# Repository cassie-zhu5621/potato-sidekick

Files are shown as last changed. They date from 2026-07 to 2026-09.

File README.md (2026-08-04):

# NoticeBot-Potato2.0

A placed sidekick that watches for one thing you asked it to watch for, and tells you
when it happens in real-time.

You say *"the roundtable area at my lab — people usually have meetings here."*
The robot turns its head across the room, photographs each angle, and sends the
five independent images to Gemini in a **single** call. Gemini enumerates what is there, sorts it
into what matters and what is only context, and compiles your sentence into a
**watch-spec** over an eleven-row vocabulary of social relations (gaze, joint
attention, pointing, F-formation, turn-taking …). CV then evaluates that spec
frame by frame, at the angle that looked richest. When the spec is satisfied the
robot collects a short photo story of the moment and looks up at you.

   what is interesting is: 
      1.you can read and argue with what it decided to watch for
      2.the whole human-robot-collaboration loop of notice delegation

---

## The hardware list

This is v2, the 3-DOF lamp form.

| | |
|---|---|
| Motions | 3 × Feetech **SCS0009** serial-bus servos — pan(id:1) / tilt(id:2) / nod(id:3) |
| Bus | **FE-URT2-C001** USB↔TTL adapter, 1 Mbaud, external 5–6 V on the servo rail |
| Head camera | **InnoMaker OV4688** UVC module, 4 MP, H-FOV 58° |
| Microcontroller | **M5Stack CoreS3** — screen, speaker, TTP223 body-tap sensor, Grove Chainable RGB LED (P9813) |
| Body | simply designed 3-DOF lamp form (built in rhino)|
| Reasoning Brain | laptop. Everything runs here; the boards are I/O. |

---

## Running it

**On a new machine, start at `docs/GETTING_STARTED.md`.

```bash
pip install -r requirements.txt

# tier 0 — logic only, no hardware at all
python3 tests/test_session_flow.py

# tier 1 — MOTION ONLY. Servos and nothing else: no camera, no VLM, no API key.
export NOTICEBOT_PORT=/dev/cu.usbmodemXXXXX     
python3 robot/clip_player.py S7a                # one state
python3 robot/clip_player.py                    # every state
python3 robot/clip_player.py --all --cores3 /dev/cu.usbmodemXXXX     # every state, with LED and sound

# tier 2 — the full loop
export GEMINI_API_KEY=...                               # Planner + five-frame confirm
python3 noticebot_loop.py --cam 0 --cores3 /dev/cu.usbmodemXXXX --serve --feedback console
```

Before trusting a session: `python3 robot/tools/preflight.py` — a check for connection. will print a GO if everything's ok.

### Local CV smoke test

The default detector is Grounding DINO; MediaPipe Tasks supplies pose and face
landmarks. Bring up only that stack, without the robot, camera, VLM API, or
speech dependencies:

```bash
python3 -m venv .venv
.venv/bin/pip install -r requirements-cv.txt
.venv/bin/python -m pytest tests/test_cv_unit.py -q
.venv/bin/python perception/cv_smoke_test.py path/to/person.jpg \
  --vocab person,cup,laptop

# optional faster open-vocabulary adapter (same smoke-test contract)
.venv/bin/python perception/cv_smoke_test.py path/to/person.jpg \
  --detector yoloworld --vocab person,cup,laptop
```

The first real run downloads `IDEA-Research/grounding-dino-tiny` into the local
Hugging Face cache. Later runs are local. Inspect `session_feed/cv_smoke/result.json`
and `overlay.jpg` for boxes, pose, face count, device, and per-stage latency.

The explicit real-model integration test uses the same function:

```bash
CV_TEST_IMAGE=path/to/person.jpg .venv/bin/python -m pytest \
  tests/test_cv_integration.py -m integration -s
```

That integration test exercises both Grounding DINO and YOLO-World. Grounding
DINO remains the default; choose `--detector yoloworld` when latency matters.

### Gemini video trigger smoke test

Put `GEMINI_API_KEY=...` in the ignored `.env` file, then pass one local video and
one text trigger condition:

```bash
python3 planning/gemini_video_trigger.py path/to/video.mp4 \
  "当有人挥手时触发反馈"
```

The default model is `gemini-3.5-flash`, with minimal
thinking, low media resolution, a 256-token output cap, and priority service
tier. Every value can be overridden through `.env` or CLI flags. The command
prints structured JSON containing `feedback_trigger`, confidence,
evidence timestamps, and a short Chinese feedback message. The uploaded test file
is deleted from the Gemini Files API after the request.

---

## What is where

```
noticebot_loop.py   MAIN — the only process
robot/              servos: bus, calibration, clip playback, firmware, CAD
motion/             the movement design: Blender sources, generators, clips
perception/         CV: detectors, pose, the 11-row relation engine
planning/           VLM: the planner, the relevance layer, the sweep
session/            the state machine, speech, storyboard, CoreS3, the feed
webui/              the researcher's browser view
docs/               specs and setup
tests/              pure-logic tests, no hardware needed
```

Every package's `__init__.py` says in a few lines what that package owns and what
each file in it does. Start there, then `docs/ARCHITECTURE.md` for how the layers
hand off.

---

## How to work on this
(manage the folders properly!!!)
| If you are changing… | you live in | you should not need to touch |
|---|---|---|
| how the robot moves | `motion/`, `robot/` | perception, planning |
| what counts as a relation | `perception/` | motion, the web UI |
| what the VLM is asked, and how its answer is compiled | `planning/` | motion, firmware |
| the interaction — screens, timing, sound | `session/`, `robot/firmware/` | perception |
| what the researcher sees | `webui/` | everything else |

!!!!!!!!!!!!Three important conventions: breaking each one has already cost us a day!!!!!!!!!!!!

1. **The CSVs in `motion/clips/` are build artefacts. Never hand-edit one.**
   To change a movement, edit the `.blend` in `motion/src/` (or the generator in
   `motion/blender/`) and re-export. A hand-edited CSV looks fine, then disagrees
   with the file it came from, and nobody can tell afterwards which one is real.

2. **`robot/calibration.py` describes THIS physical build.** Those numbers were
   *measured*, with `robot/tools/jog.py` — not chosen. If you rebuild the neck,
   re-measure. Do not nudge values until it looks right.

3. **One owner per channel.** The screen belongs to the state machine, the
   antenna's colour to the state table, its brightness to the playing clip.

---

## Specs

- `docs/GETTING_STARTED.md` — **start here on a new machine**
- `docs/ARCHITECTURE.md` — the four layers and what crosses between them
- `docs/INTERACTION_SPEC.md` — every trigger, screen and timeout, and why
- `docs/HARDWARE_SETUP.md` — wiring, servo IDs, calibration, flashing
- `docs/MOTION_AUTHORING.md` — the Blender workflow
- `docs/relation_table.md` — the eleven-row relation vocabulary, with citations
- `docs/TEST_PLAN.md` — pre-test finished, replace with user study design?

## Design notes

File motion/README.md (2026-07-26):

# motion — the movement design

```
src/        one .blend per state (plus rig.blend, the master rig)
blender/    scripts run INSIDE Blender: the rig builders, the clip generators,
            and export_clip.py
clips/      the exported CSVs the robot actually plays -- BUILD ARTEFACTS
```

Read `../docs/MOTION_AUTHORING.md` before changing anything here. The one rule:
never hand-edit a file in `clips/`.

A CSV row is `t_ms, pan_deg, tilt_deg, nod_deg, pan_unit, tilt_unit, nod_unit,
led`. `*_deg` is Blender's frame (positive nod = UP); `*_unit` is the Feetech
0-1023 position with the rig zero at 512. `led` is the antenna envelope, 0-255,
authored alongside the motion so the light and the movement cannot drift apart.

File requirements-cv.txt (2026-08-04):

# Local CV stack: Grounding DINO + MediaPipe Tasks + tests.
# Install this file instead of the full robot/speech stack when bringing up CV.
numpy
opencv-contrib-python
mediapipe
torch
transformers
pillow
ultralytics
pytest

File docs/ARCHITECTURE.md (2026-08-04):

# Architecture

Four layers, one conductor. `noticebot_loop.py` is the only long-running process;
everything else is a library it drives.

```
                       ┌──────────────────────────────┐
   participant ──PTT──▶│  session/   state machine    │◀── researcher (webui/)
   participant ──tap──▶│  S1…S8, screens, sound, STT  │
                       └───────┬──────────────┬───────┘
                    state name │              │ request text
                               ▼              ▼
                       ┌───────────────┐  ┌──────────────────────┐
                       │   robot/      │  │     planning/        │
                       │ clip player   │  │ sweep → ONE Gemini call│
                       │ → SCS0009 ×3  │  │ → watch-spec + tiers │
                       └───────┬───────┘  └──────────┬───────────┘
                     pose, deg │                     │ detect / focus vocab
                               ▼                     ▼
                       ┌──────────────────────────────────────────┐
                       │            perception/                   │
                       │ detector → scene graph → 11-row truth    │
                       │ → WatchExecutor → fired entries          │
                       └──────────────────┬───────────────────────┘
                                          │ a finding
                                          ▼
                              session/storyboard → session/feed
```

## The order of a round, and why it is that order

**S1 idle → S2 listen.** PTT held on the CoreS3. Audio is captured on the
*laptop* mic, not the board: 16 kHz 16-bit mono is 32 kB/s and the serial link
carries about 14 kB/s.

**S2 → S3 acknowledge.** Whisper returns text. The nod and "I heard you." are one
act and neither happens until the words exist — nodding earlier would claim
understanding of something not yet read. Unusable text (silence, one syllable,
punctuation) goes to S8 instead, visibly.

**S3 → S4 plan.** The head sweeps its stations and grabs **one pure frame per
station** — no detector, nothing drawn. Annotating a frame before the model reads
it feeds our own guesses back as its judgement.

**End of S4: the single Gemini call.** The five raw frames are sent as separately
labelled spatial images in one request. A grid is written only for local researcher
visualization and is not model input. Back comes:

- `seen` — everything in the room
- `detect` — context tier: enriches, cannot trigger
- `focus` — may trigger
- `boxes` — per object, mapped back to the angle it came from
- `watch` — the compiled spec, over rows 1–11

**S4 → S5 track.** The clip ends before the VLM does, so the head **holds the last
angle it swept** and the screen keeps saying `planning...`. Only when the answer
lands does it turn to the richest-scoring angle and say `tracking...`. Claiming to
track while the answer is in flight is a statement about the robot's state that
is simply untrue.

**S5 watching.** `focus`/`detect` become the detector's vocabulary — `set_vocab`
for an open-vocab model, a synonym-expanded whitelist for closed COCO YOLO. Each
settled frame produces a truth vector; `WatchExecutor` decides which entries are
satisfied; `_focus_ok` refuses any gaze or point that did not land on a focus
object. Without that last gate, "someone looked at something" fires on every
chair in the room.

**A fired entry → candidate → Gemini confirm.** A raw-frame ring buffer selects
five ordered frames at t−1, t−0.5, onset, t+0.5 and t+1 seconds. Only a confirmed
candidate is reported. The safe default is one console feedback line; S7 motion
requires explicit `--feedback robot`.

**S6, "not that one."** A body tap during S5. The watch-spec survives; only the
direction changes. If nobody answers within 15 s the robot moves to the *next-best*
angle from the sweep rather than back to the rejected one.

## Rules that cross layer boundaries

**Frames are only used when the head is still.** `settled_ms > SETTLE_MS`. A
frame grabbed mid-move is blurred *and* attributed to a pose the head has already
left.

**Perception may fail forever without anything else noticing.** The state
machine, the screens and the researcher's keys do not depend on it. A run that
dies mid-study costs a participant.

**Every finding goes through one door.** A watch entry firing, the researcher's
`f` key and a forced state all reach `session/feed.py` the same way. When the
storyboard hung off the detector while the screen counter hung off the state
machine, the board read 3 and the feed read 0 — they were counting different
events.

**One owner per channel.** Screen ← state machine. Antenna colour ← state table.
Antenna brightness ← the playing clip. Sound ← the clip's `sfx`. The v1 firmware
had legacy commands that set colour and text as *side effects*, which is how S6's
red negation got painted blue.

## Testing without hardware

`session/session_flow.py` contains the transition rules and nothing else — no
serial port, no frame grab, no sleep. `tests/test_session_flow.py` drives it with
a fake clock, 86 assertions. The awkward paths (STOP mid-scan, a transcript that
arrives after its timeout, a tap in the wrong state) are exactly the ones that are
tedious to trigger by hand and the ones a participant finds in five minutes.

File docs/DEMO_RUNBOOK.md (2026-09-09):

# DEMO RUNBOOK — the exhibition stand

Branch `demo-expo-2026`. The user-study build is `cassie/tomato`, tagged
`s2-study-build`; nothing here is meant to go back to it.

**The robot is unchanged** — same firmware, same English screen, same faces.
Everything a visitor reads is on the iPad, so translating the stand means
translating one file (`webui/booth.py`, the `CHOICES` list at the top).

---

## 0. Once — the touch sensor

A TTP223 capacitive module on the head. The only hardware the demo adds, and the
firmware already supports it (`USE_TAP 1`, `TAP_SRC 1`).

```
SIG -> GPIO 17   (Grove Port C)
VCC -> 3V3       NOT 5V. ESP32 GPIO is not 5 V tolerant.
GND -> GND
```

Check it before anything else:

```bash
python3 robot/tools/touch_test.py --cores3 /dev/cu.usbmodem11201
```

One `IN BODYTAP` per touch. Random 0/1 with nothing touching means SIG is not
reaching the pin. **No sensor to hand?** Set `TAP_SRC 2` in the `.ino` and
reflash — the onboard IMU reports a knock instead, no wiring at all.

---

## 1. Each morning — is the VLM fast today?

```bash
python3 -m robot.tools.net_check
```

Read **FLOOR** (see §2b of the main RUNBOOK):

| FLOOR | what it means |
|---|---|
| 1–2 s | planning will be 5–8 s. The sweep screen carries it easily. |
| 7–10 s | planning will be ~20 s. Still works; stand next to the visitor and talk over it. |

A slow FLOOR is Google queueing and **cannot be fixed from here** — not by the
network, not by the tier, not by sending fewer frames. Measured across two days:
RTT 0.03 s while FLOOR swung 1.3 → 20 s, and a hotspot made RTT *worse* without
touching FLOOR.

**Do not change `NOTICEBOT_GEMINI_MODEL`.**

---

## 2. Start it — ONE terminal, all day

```bash
cd ~/Documents/Claude/Projects/potatobot/notice-sidekick-runkit
git checkout demo-expo-2026

python3 noticebot_loop.py \
    --cam 0 \
    --cores3 /dev/cu.usbmodem11201 \
    --detector yoloworld \
    --cv-hz 4 \
    --feedback robot \
    --serve --conf 0.2
```

Identical to the study command. It prints two addresses:

```
open  http://localhost:8000                 <- the researcher's page
      http://192.168.x.x:8000/booth         <- type THIS on the iPad
```

**Do not restart between visitors.** Every story lands in one
`attention_log.jsonl`, and the day's wall on the tablet is that file. A restart
opens a new session folder and the wall goes empty.

There is no second terminal. The study's file server (main RUNBOOK §4b) serves a
static page that must outlive a loop restart; the tablet has to *control* the
loop, so it lives in the same server.

---

## 3. The iPad

Open the printed address in Safari, then once:

1. **共有 → ホーム画面に追加.** Opening from the Home Screen is full-screen with
   no address bar, so a visitor cannot navigate away.
2. **設定 → アクセシビリティ → アクセスガイド** on. Triple-click to lock it to
   the page.
3. **設定 → 画面表示と明るさ → 自動ロック → なし.**

### Bring your own network

Venue Wi-Fi very often has **client isolation**: two devices on the same SSID
cannot reach each other, and there is no fixing it on the day. Bring a travel
router or use a phone hotspot, and put the laptop and the iPad both on it with
the laptop reaching the internet through the same box.

Test before doors open: if `localhost:8000/booth` works on the laptop and the
iPad hangs, it is isolation.

---

## 4. What a visitor does

```
   ねている        Idle. Sleeping face on the robot AND on the iPad --
                   (-_-) z z z and one line: あたまに そっとさわって
                   ください. No menu: a stand with a list of options on
                   it is a kiosk.
1  頭にさわる      Tap -> it lifts out of the bow and looks up, and the
                   THREE CHOICES appear on the iPad.                    (S2)
                   The tap has a consequence on both screens at once,
                   which is what teaches the gesture.
2  iPadで選ぶ      Three Japanese sentences. Tapping posts the ENGLISH
                   one through the same door speech uses, so the planner
                   really compiles it.
3  うなずく        Acknowledge. 1.7 s, no page of its own -- the strip
                   shows ^o^ and the page stays put.                    (S3)
4  部屋を見る      Scan. Five stations appear on the iPad as they are
                   captured; when the plan lands the boxes are drawn and
                   the chosen one goes red.                             (S4)
5  見張る          Watch. SAME SCREEN. The red cell is now the LIVE
                   camera; the other four stay as sweep stills.         (S5)
   頭にさわる      -> Correct. It looks elsewhere and the red frame moves
                   with it.                                             (S6)
6  よぶ            Call. Chirp + lean. The same prompt appears on the
                   iPad and on the robot's screen.                      (S7)
7  OK             Either screen. The robot nods and goes straight back
                   to watching; the TABLET stays behind and waits for
                   the report -- 6-45 s, with a face and a moving bar.
8  Then the story: the strip at full height, swiped sideways, sentence
   underneath.  とじる returns to the choose screen.
```

**The tap means two things and the robot decides which** — asleep it means "look
at me", watching it means "not that one". Both are the same sentence: put your
attention where I am pointing it.

### The two extra touches on the room screen

- **Tap the red cell** → the live view fills the screen, everything else dims to
  10–14%, and the rule stays lit in the sixth cell. Tap again to go back.
- **The sixth cell is the rule** — relation chips that light as each becomes
  true, the AND/OR/THEN between them, and the object they are bound to. This is
  what tells a visitor *how to trigger it*, and it is the panel to point at when
  somebody asks how it works.

### The top strip

```
[-_-] [._.] [^o^] [・・・] [o_o] [>_<] [\^o^/]              [☰ 3]
ねてる きづいた わかった みてる  みはり ちがう よんでる        きろく
```

The faces are copied from the firmware's `uiFace()` — the same characters the
robot's own screen shows, so a visitor looking from one to the other sees the
same thing twice. `☰` opens the day's stories; it hides itself while open.

---

## 4b. The keys, from the terminal

They work in the terminal the loop was launched from — no need to click the
preview window first.

| key | does |
|---|---|
| `1`…`8`, `0` | force a state (1 Idle · 2 Attend · 3 Acknowledge · 4 Scan · 5 Watch · 0 Settle · 6 Correct · 7 Call · 8 Error) |
| `g` | S2_LISTEN — the same lift the head tap produces, for testing without the sensor |
| `f` | force a finding — the keyboard twin of **notice this NOW** |
| `r` | torque off (press a state key to re-engage) |
| `q` | quit |

Useful before the sensor is wired: `g` → tap a choice on the iPad → `f` → OK.
That walks the whole demo without touching the robot.

---

## 4c. Your break — the stand runs itself

```bash
# stop the loop first: Ctrl-C. Both open the same two serial ports.
python3 -m robot.tools.attract
```

Walks the whole eight-state cycle — motion, screen, light and sound together —
and loops until Ctrl-C. About 55 s a pass. `--gap 1.5` slows it, `--once` does a
single pass.

Each beat waits for its clip to finish and *then* holds, so a gesture is never
cut off mid-turn. Clip lengths are read from the CSVs at startup rather than
kept in a table, so re-exporting from Blender cannot make the timing stale.

A motionless robot on a table reads as broken, and one that only moves when
somebody works the tablet is invisible from across the hall.

**It is NOT the system.** No camera, no VLM, no watch-spec, nothing recorded —
authored clips on a timer. The board shows `DEMO LOOP` and the terminal says so
too, because at a research stand that reading has to be corrected before it is
made, not after somebody has told a colleague about it. If anyone asks whether
it is really watching right now: no, and start the real loop to show them.

Ctrl-C releases the joints, so the head does not fight the next person who picks
the robot up to look underneath.

---

## 5. When it does not fire

Both controls are on the **laptop's** page (`http://localhost:8000`, LIVE tab,
**IF IT MISSES THE SCENE**):

- **notice this NOW** — skips the trigger and the confirmation judge. The robot
  performs the notice and collects the story exactly as if it had fired. The
  visitor cannot tell.
- **look around again** — a fresh sweep on the same request.

Give it ten seconds first. A real trigger is better than a forced one, and the
visitor is usually still reading the tablet.

---

## 6. What is different from the study build

Worth knowing, because someone will ask:

| | study | stand |
|---|---|---|
| brief | spoken, Whisper | two Japanese buttons → the same English sentence → the same planner |
| `REPLAN_PERIOD_S` | 540 s — one self-directed sweep per session | **0** — at a stand it lands mid-visit and reads as a fault |
| tablet | review page only, second process | the whole interface, in the loop's server |
| head tap | Correct only | Correct **and** wake |

The VLM path is **byte-identical** to `s2-study-build`: `perception/`,
`planning/planner.py`, `planning/judge.py`, `planning/provider.py`,
`planning/gemini_provider.py`, `robot/`, `motion/` — no diff. The only change
under `planning/` is `sweep_plan.py` recording its own output directory, which
no prompt ever sees.

---

## 7. Changing the wording

`webui/booth.py`, `CHOICES` at the top. Japanese for the visitor, English for
the planner; **the planner never sees Japanese**. Restart the loop.

The three shipped are:

| | asks for | why |
|---|---|---|
| 荷物に触ったら教えて | hands-on the visitor's own bag | "that is mine" is what makes delegating mean anything |
| 人が集まったら教えて | gathering | ambient; a crowded hall supplies it for free |
| ポスターの前で発表がはじまったら教えて | people gathering **in front of a poster** | **the room the stand is actually in** — presentations start at the posters all day. Costs the visitor nothing to arrange, happens whether or not anyone waits for it, and makes the point better than a staged event could. Bound to the poster, which is what keeps it from compiling to the same entry as `gather` |

Keep it to three or fewer. A visitor deciding between two or three things reads
them; a visitor deciding between five picks the first one.

---

## 8. End of the day

Ctrl-C once. The teardown flushes any story still collecting, so the last
finding of the day is on disk rather than lost with the process.

`session_feed/<run>/` is the whole day: every report, every sweep, every LLM
call, and `review.html`.

---

## Troubleshooting

| symptom | first suspect |
|---|---|
| iPad hangs, laptop is fine | venue Wi-Fi client isolation (§3) |
| tablet stuck on the choose screen | the loop is not publishing — check the terminal for a traceback |
| tapping the head does nothing | `touch_test.py` first; then whether the robot is in the state that accepts it |
| nod, then sleep, no sweep | an `arm_next` ordering regression — every caller must `request()` first and `arm_next()` second |
| the wall is empty | the loop was restarted; the wall is one `attention_log.jsonl` |
| planning takes 20 s | `net_check`. If FLOOR is high it is Google, and nothing here helps |
| the live cell flickers black | the stream got moved inside the markup `render()` rewrites — it must stay outside `#app` |
| in `attract`, the screen changes but nothing moves | `player.start()` is missing — `request()` only records what the player should do; a worker thread feeds the bus. It looks exactly like a servo-power fault and is not |
| the robot fights your hand | you are in `attract` and it has not been Ctrl-C'd, or a state key re-engaged torque. `r` releases |
| keyboard keys do nothing | fixed 2026-09-09 — the terminal used to be read only under `--no-view`, so with a preview window open `f`, `g` and the state numbers only worked when THAT window had focus. If it regresses, look for an `a.no_view` gate on `stdin_key()` |

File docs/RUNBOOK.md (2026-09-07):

# RUNBOOK — bringing the robot up, in order

The order matters. Each step isolates one layer, so that when something breaks
you already know which layer it is in. Skipping to step 3 and debugging from
there is how a servo problem gets mistaken for a CV problem.

`MACHINE_E2E_READINESS.md` is the longer bring-up narrative; this is the short
version you run every time.

---

## 0. Once per machine — dependencies

```bash
conda activate sidekick
cd ~/Documents/Claude/Projects/potatobot/notice-sidekick-runkit

pip3 install -r requirements.txt -r requirements-cv.txt
pip3 install feetech-servo-sdk python-dotenv google-genai ultralytics
```

The second line is the packages whose **pip name differs from their import
name**, or that the requirements files miss. They were each discovered the hard
way — one at a time, mid-run, after the robot had already been woken up:

| pip name | import name | why it is not obvious |
|---|---|---|
| `feetech-servo-sdk` | `scservo_sdk` | `pip install scservo-sdk` installs nothing useful |
| `python-dotenv` | `dotenv` | missing from `requirements.txt` |
| `google-genai` | `google.genai` | `google` is a namespace package, so it "exists" while empty — the error says `cannot import name 'genai'`, not "not installed" |
| `ultralytics` | `ultralytics` | only needed for `--detector yoloworld` |

Also: `.env` must exist (copy `.env.example`, add `GEMINI_API_KEY`). Not needed
for `--offline`.

### Which LLM answers

One variable, read in one place (`planning/provider.py`). Unset means Gemini, so
a fresh clone and the other machine behave exactly as before.

```
NOTICEBOT_LLM_PROVIDER=gemini       # default
NOTICEBOT_LLM_PROVIDER=anthropic    # + ANTHROPIC_API_KEY, + pip3 install anthropic
```

Try a provider **before** a session, on a sweep that already happened, rather
than discovering it with a participant in the room:

```bash
python3 robot/tools/provider_ab.py                    # newest recorded sweep
python3 robot/tools/provider_ab.py --provider both    # re-run both, live
```

The provider also selects the station-scoring rule (`planning/station_score.py`),
because that rule counts boxes and the two models do not box at the same density
— Gemini's is kept verbatim, Anthropic's caps what context boxes can contribute.
`plan.json` records both, and the sweep line prints them.

It prints the recorded answer beside the new one: latency, violations, watch
entries, boxes. **The boxes are the ones to read.** Their coordinate convention
lives in the prompt, not in the schema, so a model that reads it differently
returns numbers that are individually plausible and jointly wrong — a failure
that passes validation, passes the test suite, and shows up as the robot aiming
confidently at nothing.

---

## 1. No hardware — 30 seconds

```bash
python3 -m robot.states              # state table vs clips vs source literals
python3 tests/test_session_flow.py   # pytest CANNOT collect this one
python3 -m pytest -q
```

`test_session_flow.py` is an old-style script with no `test_` functions, so
`pytest` reports "no tests ran" and moves on. It is the only test of the state
machine. **Run it separately or it is silently skipped.**

Run this before touching the robot. It catches a broken state table, a stale
clip, and a mistyped state name — none of which need a servo to find.

---

## 2. Hardware health

```bash
python3 noticebot_loop.py --list-cams        # confirm the head cam's index
python3 robot/tools/preflight.py --cam 0     # bus / calibration / clips / camera
```

Wants `GO`. Notes:

- The head camera is the one that **actually delivers 2560×1440**. The built-in
  returns a square frame (Center Stage). Indices move whenever anything USB is
  replugged, so this is a per-session check, not a number to write down.
- Voltage: `< 5.5` warns, `< 5.0` fails. **Under-voltage does not raise — it
  makes the motion soft, slow and short of its target, which reads exactly like
  a calibration error.** Swap the pack before blaming a curve.

---

## 2b. Is the VLM fast today? — 40 seconds, before the participant arrives

```bash
python3 -m robot.tools.net_check          # 5 reps; pass a number for more
```

Planning latency is **not stable across days and is not ours to control**. On
2026-08-17 the planner's median went from 5.7 s (the previous week) to 18.6 s,
peaking at 49 s, with nothing changed on our side — same model, same thinking
level, same ~5460 input tokens. Knowing that at 09:00 is a schedule decision;
finding out at 14:05 with somebody in the chair is a lost session.

Three numbers, because they fail for different reasons:

| | what it measures | reading |
|---|---|---|
| **RTT** | TCP+TLS to the endpoint. No API key, no quota | `> 1 s` → the network. Try a hotspot |
| **FLOOR** | a call with a ~100-byte payload and an 11-token answer | `> 4 s` → **Google is queueing.** Nothing on this machine helps |
| **LOADED** | the same call carrying five real JPEGs, ~530 KB | `LOADED − FLOOR` big → the uplink or image ingestion |

It prints a verdict. **A slow FLOOR is the common case and it is not fixable** —
bandwidth cannot explain seconds for a hundred bytes. Measured 2026-08-17: Wi-Fi
RTT 0.03 s with FLOOR 7.7 s, and a hotspot made RTT *worse* (0.11 s) without
touching FLOOR. Do not go looking for a better connection.

**What to do when FLOOR is slow**

- Budget ~20 s for brief→watch and **push E1's cue later**, so the actor is not
  playing the scene while the robot is still sweeping.
- Do **not** change `NOTICEBOT_GEMINI_MODEL` mid-study, however tempting. Half of
  S2 is already on `gemini-3.5-flash`; a model change splits the dataset and
  makes the planner's relation choices incomparable across participants. (3.5 is
  two generations behind as of 2026-08-13 — 3.6 shipped 07-21, 3.7 on 08-13 —
  which is the most likely reason it is being served slowly. It is still not
  worth the confound.)
- Check <https://status.cloud.google.com/> — but the 08-17 slowdown was never
  posted there, so an all-green status page is not evidence.

---

## 3. Motion only — no perception, no cloud

```bash
python3 robot/clip_player.py --cores3 /dev/cu.usbmodem11201
```

Walks the whole CYCLE and reports lag and dropped frames.

**Pass: 0 dropped, worst lag under 20 ms.**

This is the step that separates *servo / power / timing* from *perception /
planning*. If it is clean here, no later motion problem is the detector's fault.
Single clips for a faster look:

```bash
python3 robot/clip_player.py S7a    # the most demanding: pan peaks at 121 deg/s
python3 robot/clip_player.py S7b    # holds the deep -22 lean under load
python3 robot/clip_player.py S4_PLAN
```

LED-only, touching no servos — separates "firmware not reflashed" from
everything else:

```bash
python3 robot/clip_player.py --led-test --cores3 /dev/cu.usbmodem11201
```

---

## 4. Full loop

```bash
python3 noticebot_loop.py \
    --cam 0 \
    --cores3 /dev/cu.usbmodem11201 \
    --detector yoloworld \
    --cv-hz 4 \
    --feedback robot \
    --serve
```

Web UI at **http://localhost:8000** — live view, plan, feed, and the context box
(type a request there instead of speaking).

| flag | why |
|---|---|
| `--detector yoloworld --cv-hz 4` | the detector, and the only one. Now also the default; `gdino` is kept selectable for reproducing old logs and is never run |
| `--feedback robot` | let a confirmed finding drive S7. `console` prints the judgment and moves nothing |
| `--offline` | no Gemini; use it to prove the mechanics before adding cloud latency |
| `--no-stt` | skip Whisper; type into the web context box |
| `--cores3 <port>` | explicit beats auto-detect when you already know the port |

```
1-8 force a state · 0 S5a · f manual finding · c cycle · r relax · q quit
```

Those keys are read from the **OpenCV preview window** when it is open, and from
the **terminal** when it is not (`stdin_key()`, cbreak on a tty). So `--no-view`
costs the preview window, not the override — earlier revisions of this file said
it "takes the keyboard with it", which was never true of the code.

**Use `--no-view` whenever `--serve` is on.** The OpenCV window is a native
window and can never render inside the browser page; leaving it open just means
two copies of the same stream, one of which steals focus. The web UI has already
had the live view at `/stream.mjpg` since it was written. With `--no-view
--serve` the annotated frame is still computed and published — the flag suppresses
the window, not the overlay.

---

## 4b. The participant's screen — a SECOND terminal

The tablet beside the robot shows the reports. It needs a plain file server,
because `file://` forbids the `fetch` the page uses to notice new reports:

```bash
cd ~/Documents/Claude/Projects/potatobot/notice-sidekick-runkit/session_feed && \
python3 -m http.server 8765 --bind 0.0.0.0
```

**The full path and the `&&` both matter.** This was two lines with a relative
`cd`, and run from anywhere but the project's parent the `cd` fails while the
shell goes on to the next line anyway — so the server comes up happily, serving
whatever directory you happened to be in. It looks like it worked; the tablet
just says 404 for `latest.html`. Hit on 2026-08-17 from the home directory.

Leave it running all day. Point the tablet at, once, and never again:

```
http://localhost:8765/latest.html      # on the laptop itself, or a Sidecar iPad
http://<laptop-ip>:8765/latest.html    # ipconfig getifaddr en0
```

`latest.html` follows `current.txt`, which the loop rewrites at startup, so it
tracks the current run across participants and across restarts without anybody
retyping a session name.

**A SEPARATE PROCESS ON PURPOSE.** Serving this from the `--serve` web UI would
be one window fewer and was rejected for it: the two would then die together, and
the moment that matters is a mid-session restart of the loop. The participant is
sitting in front of the tablet; it should keep showing the last report rather
than "cannot connect".

**Do not put this on the participant's phone.** The questionnaire's
imagined-camera block and interview Q6 both turn on the contrast with *phone
alerts*; delivering the reports by phone answers that question before it is
asked. A fixed screen that is not theirs is the point.

If the tablet cannot reach the laptop, suspect the venue's WiFi before anything
else — campus networks commonly isolate clients from each other, and then no IP
will work. `curl -sI http://<laptop-ip>:8765/latest.html` FROM THE LAPTOP splits
it: a 200 means the server and firewall are fine and the block is between the
devices. Sidecar, or a phone hotspot both machines join, sidesteps it entirely.

---

## 5. Shut down — every time

```bash
python3 robot/tools/play_on_hardware.py --relax
```

Ctrl-C runs the cleanup. **Closing the terminal window or `pkill` does not**:
the `finally` block never executes, so torque stays on and the servos hold their
last pose, heating, and the CoreS3 keeps whatever colour it was showing. Check by
hand — a relaxed neck moves freely.

---

## Reading a failure

| symptom | first suspect |
|---|---|
| `no CoreS3 found` | another process owns the port (Arduino IDE's serial monitor); then firmware |
| tablet says "waiting for a session…" forever | the loop has not started, or it is writing to a `--feed-dir` outside `session_feed/`. `cat session_feed/current.txt` |
| tablet shows the previous participant's reports | the loop never started for this one; `current.txt` is written before anything else can fail, so it is a run that did not run |
| tablet page never updates | opened as `file://`, not through the server — `fetch` is blocked there and the poll dies silently |
| planning takes 20–50 s and the participant is waiting | almost never ours. `python3 -m robot.tools.net_check` (§2b). A slow FLOOR is Google queueing and cannot be fixed from here |
| `404` for `latest.html` on a server that started fine | the `cd` failed and the shell ran `http.server` anyway, so it is serving the wrong directory. The 404 line is the give-away: the server is up, the file is not there. Use the full path with `&&` (§4b) |
| `PONG cores3_sidekick v4` after flashing | the board still has the old build; v5 is STOP-as-hold, OK-only on `noticed`, OK on `error` |
| LED never changes | no `--cores3`; then firmware; then a flat `led` column in the CSV (re-export) |
| transcript comes back empty | microphone permission for Terminal — macOS hands out a **silent stream** rather than an error |
| stuck on the `waiting` bar | Whisper is running; `stt_busy` postpones the 15 s deadline up to a 30 s ceiling. Press STOP: if it responds, the main loop is alive |
| motion soft / short of target | battery, not calibration |
| BODYTAP with nobody touching it | TTP223 SIG floating. Harmless in S1 — **in S5b every false tap is an S6** |
| `ignoring model '…' — not a Claude model` | a `NOTICEBOT_GEMINI_*` model variable is still set while the provider is `anthropic`. It is being dropped, which is the correct outcome; clear it to silence the line |
| `404` / `not_found_error` on the Anthropic path | the model name. `NOTICEBOT_ANTHROPIC_MODEL` overrides it without validation |
| `ran out of output budget` | raise `NOTICEBOT_ANTHROPIC_MAX_OUTPUT_TOKENS` (default 4096). On the Gemini path the same cause surfaces as `parse-fail: Expecting ',' delimiter` instead |

The run's artefacts, including every LLM call, land in
`session_feed/e2e_<timestamp>/`. Failed calls are audited too.

---

## Branches

Naming follows the existing `sonan/…` convention:

```bash
git checkout -b cassie/<what>
git add -A && git commit -m "..."
git push -u origin cassie/<what>

git fetch origin
git rebase origin/sonan/modification
```

Before pushing, the three checks from step 1. Note that changing
`generate_s4_sweep.py` **will** turn `test_sweep_plan.py` red: it hard-codes S4's
old structure (`led == 223`, a return of `> 200` units). That is the test
asserting the bug you are removing, and it has to be updated with the generator.

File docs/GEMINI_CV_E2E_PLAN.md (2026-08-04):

# NoticeBot Gemini + CV 重构与本机 E2E 计划

> 状态：Gemini production path 已实现；stable entity IDs 等增强项继续迭代  
> 分支：`sonen/modification`  
> 目标：用户用一句自然语言委托 NoticeBot；系统用本机 webcam、CV 和 Gemini 找到对应事件；确认后只在终端输出一行反馈，不控制舵机、CoreS3、灯光或声音。

真机到货后的安全顺序、GO/NO-GO 和剩余接口见 `docs/MACHINE_E2E_READINESS.md`。

## 0. 一句话版本

```text
用户输入 → Gemini 看 5 个空间视角并生成可执行 Plan → CV 在本地约 1 Hz 持续观察
→ CV 候选事件触发 → 取同一视角前后 5 帧给 Gemini 确认 → 终端输出一行反馈
```

核心原则：**Gemini 负责理解“用户想看什么”和最终确认；CV 负责低成本、持续地找候选事件。** Gemini 不逐帧运行。

---

## 1. 当前代码和目标架构的区别

| 项目 | 迁移前 | 当前实现 |
|---|---|---|
| Planner 模型 | Anthropic Claude | Gemini，模型名可通过环境变量切换 |
| Planning 图像 | 多视角拼成 1 张 contact sheet | 5 张独立空间帧，在同一次 Gemini 请求中依次传入 |
| CV 输出 | 全局 `relation_id -> bool` | 带人物、目标物、时间和证据的 `RelationFact` |
| 触发后流程 | CV fired 后直接进入 finding/story | CV 先生成 candidate，再由 Gemini 看 5 张时间帧确认 |
| Judge | Anthropic；主要在 story 最后调用 | Gemini；在进入 finding 前调用，返回结构化 JSON |
| 用户反馈 | Story/feed，以及机器人动作 | MVP 只输出一行：`[FEEDBACK] ...` |
| 纯电脑 webcam E2E | 主入口仍强制连接舵机，不能真正独立运行 | 增加 `--robot none --feedback console` |
| Gemini 视频脚本 | 已有独立 smoke test，上传整段本地视频 | 保留作实验工具；正式实时链路使用 5 张图片，不上传持续视频 |

`planning/gemini_video_trigger.py` 保留为独立 whole-video smoke test；production 主循环通过共享 Gemini provider 完成独立空间图片 Planning 和五时间帧 Confirm。

---

## 2. 会用到哪些 Service、Key 和本地组件

### 2.1 Service / Key 总表

| Service / 组件 | 用途 | 是否联网 | 需要的 Key / 配置 | MVP 是否必须 |
|---|---|---:|---|---:|
| Gemini Developer API | 5 视角 Planning；5 时间帧 Event Confirm；生成一行反馈 | 是 | `GEMINI_API_KEY`、`NOTICEBOT_GEMINI_MODEL` | 是 |
| OpenCV | webcam 读取、帧缓存、JPEG 编码、预览和 overlay | 否 | camera index，如 `--cam 0` | 是 |
| MediaPipe | Face landmarks、head pose、人体 pose、手腕/肩/髋关键点 | 首次模型准备后本地 | 无 Key；模型在 `perception/weights/` | 是 |
| Ultralytics YOLO-World | 可切换的低延迟 open-vocabulary detector；后续可接 ByteTrack | 首次下载权重时联网 | 无 Key；公开权重自动下载 | 否，但保留并测试接口 |
| Grounding DINO | open-vocabulary detector 备选 | 首次下载模型时联网 | 公开模型通常无需 Key；必要时可用 `HF_TOKEN` | 否 |
| faster-whisper | 本地语音转文字 | 首次下载模型时联网 | 无 Key；`NOTICEBOT_WHISPER`、`NOTICEBOT_LANG` | 否，本机测试先文字输入 |
| Web UI | 输入用户请求、查看 raw/overlay、Plan 和事件 | 否 | `--serve --web-port 8000` | 建议 |
| Servo / CoreS3 | 机器人转头、屏幕、灯光、声音 | 否 | 串口配置 | 此阶段不使用 |
| 数据库 / 云存储 | 不需要；Plan、事件、图片先写本地 | 否 | 无 | 否 |

Gemini 参考文档：[Models](https://ai.google.dev/gemini-api/docs/models)、[多图理解](https://ai.google.dev/gemini-api/docs/image-understanding)、[Structured Output](https://ai.google.dev/gemini-api/docs/structured-output)。

### 2.2 推荐环境变量

`.env` 只放本机秘密，不进入 Git：

```dotenv
GEMINI_API_KEY=replace_with_your_real_key

# 不把模型名写死在业务代码里。低延迟 smoke test 使用 Flash-Lite；
# 若账户可用模型不同，只改这里。
NOTICEBOT_GEMINI_MODEL=gemini-3.5-flash
NOTICEBOT_GEMINI_THINKING_LEVEL=minimal
NOTICEBOT_GEMINI_MEDIA_RESOLUTION=low
NOTICEBOT_GEMINI_MAX_OUTPUT_TOKENS=256
NOTICEBOT_GEMINI_SERVICE_TIER=priority

# 本机默认参数，不是秘密
NOTICEBOT_CAMERA=0
NOTICEBOT_CV_HZ=4
NOTICEBOT_LANG=zh
NOTICEBOT_FEEDBACK=console
```

兼容现有 smoke test 时，可以暂时同时支持 `GEMINI_MODEL`；重构完成后统一为 `NOTICEBOT_GEMINI_MODEL`。

### 2.3 Key 管理规则

1. 仓库只提交 `.env.example`，绝不提交 `.env`。
2. Key 只在 provider 初始化时读取；不能放进 prompt、Plan JSON、日志或 Web UI state。
3. 启动时只打印 `Gemini configured: yes/no`，不能打印 Key 的任何片段。
4. API 错误日志要过滤 request headers 和完整 payload。
5. 测试使用 fake provider，不依赖真实 Key，也不产生费用。
6. 如果 Key 曾被提交或贴进聊天，应立即在 Google AI Studio 撤销并重新生成。
7. 后续部署到共享机器时用系统 secret manager；本机 prototype 用 ignored `.env` 足够。

---

## 3. CV 包括什么

| CV 模块 | 输入 | 输出 | 建议实现 |
|---|---|---|---|
| Camera | webcam 原始视频，通常约 30 FPS | timestamped BGR frame | OpenCV `VideoCapture` |
| Frame sampler | camera frame | 默认 1 Hz perception frame；5 张 planning/event frame | OpenCV + ring buffer |
| Object detector | perception frame | 带置信度的物体 boxes | 默认 Grounding DINO；保留已测试的 YOLO-World adapter |
| Tracker | 连续 detections | 稳定的 `person_1`、`laptop_1` 等 entity id | Ultralytics ByteTrack，先不加新包 |
| Face / gaze | frame + person | face、head pose、gaze ray | MediaPipe FaceLandmarker + OpenCV geometry |
| Body pose | frame + person | shoulders、hips、elbows、wrists | MediaPipe PoseLandmarker |
| Relation evaluators | entities + tracks + pose | `RelationFact[]` | 11 个固定 evaluator |
| Trigger matcher | Plan + RelationFact stream | `EventCandidate` | onset + persist + sequence + cooldown |
| Event frame buffer | timestamped raw frames | 同一视角的 5 张时间帧 | 内存 ring buffer |
| Overlay | detections + tracks + facts | 只供人调试的画面 | OpenCV；绝不作为 Gemini 原始输入 |

### 3.1 11 种关系

| ID | Relation | 主要 CV 证据 | 是否需要目标绑定 |
|---:|---|---|---:|
| 1 | gazing-at | face/head ray 命中 object box | 是 |
| 2 | joint-attention | 两条 gaze ray 指向同一 target | 可选 |
| 3 | eye-contact | face forward 指向 camera | 否 |
| 4 | pointing/reaching | elbow→wrist ray 命中 target | 可选 |
| 5 | proxemic-zone | 人际距离 / shoulder width | 否 |
| 6 | F-formation | 多人朝向和共同 o-space | 否 |
| 7 | approach/depart | tracked distance 在时间窗内单调变化 | 可选 |
| 8 | lean-in | torso angle 朝指定 work surface / object | 是 |
| 9 | hands-on | wrist 进入/接近指定 object box 并持续 | 是 |
| 10 | gathering | person count 或 group cluster 改变 | 否 |
| 11 | turn-taking | 指定 shared artifact 的 controller id 改变 | 是 |

不要只输出 `truth[9] = true`。目标格式是：

```json
{
  "relation_id": 9,
  "relation_key": "hands_on",
  "subject_id": "person_1",
  "target_entity_id": "laptop_1",
  "confidence": 0.86,
  "started_at": 1720000000.25,
  "observed_at": 1720000001.25,
  "evidence": {
    "wrist": "right",
    "wrist_inside_target": true,
    "held_for_s": 1.0
  }
}
```

这样 `hands-on laptop` 不会被“手碰到了 cup”错误触发；`then` 也能保证是同一个 tracked person 完成前后动作。

### 3.2 采样率

| 数据 | 建议采样方式 | 原因 |
|---|---|---|
| webcam capture | 相机原生约 30 FPS | 让预览和 ring buffer 连续 |
| CV inference | Grounding DINO 接受约 **1 Hz**；YOLO-World 接口可切换到更高频率 | 用户选择准确/open-vocab 优先，同时保留低延迟路径 |
| Planning frames | 用户输入后 **5 张空间帧**，每个视角 1 张 settled raw frame | 看完整环境，不是时间序列 |
| Event frames | 候选 onset 周围 **5 张时间帧**：`t-1.0, t-0.5, t0, t+0.5, t+1.0 s` | 看 before / during / after |
| Gemini calls | 每次新 Plan 1 次；每个通过本地 gate 的 candidate 最多 1 次 | 不逐帧调用，控制延迟与费用 |

CV 的推理频率不代表相机帧率。相机仍连续采集；Grounding DINO 可以约 1 Hz 运行，YOLO-World 在需要低延迟时通过同一 detector interface 切换。Event buffer 从 raw stream 里按目标 timestamp 选最近的 5 帧。

---

## 4. 两类“五帧”到底是什么

### A. Planning 的 5 张空间帧

```text
view_1(-60°) → view_2(-30°) → view_3(0°) → view_4(+30°) → view_5(+60°)
```

它们是**大致同一时段、不同观察角度**。目的：让 Gemini 理解房间里有哪些人和物、用户说的对象在哪个视角、接下来应该监视哪里。

无机器人时，webcam 不能自己转头，因此提供两种模式：

- `--planning-view fixed`：复制/采集同一 webcam 方向的 5 张短间隔帧，用于最简单 E2E；不声称覆盖整个房间。
- `--planning-view manual`：UI 提示用户把 webcam/电脑依次朝 5 个方向，每次按空格采一张，更接近真实 sweep。

有机器人后再恢复 5 个 pan station 的自动 sweep。

### B. Event Judge 的 5 张时间帧

```text
t-1.0s → t-0.5s → t0(candidate onset) → t+0.5s → t+1.0s
```

它们是**同一观察角度、不同时间**。目的：确认动作是否真的发生以及方向，例如 approach 还是 depart、谁把 control 交给了谁。

五张图片都作为独立 image part 放在同一次 Gemini 请求中，并在每张图前放一个明确 label；不拼图，不逐张发五次 API。

---

## 5. Tentative Prompts

Prompt 不应要求模型暴露 chain-of-thought。我们给模型的是可审核的 `evidence_chain` 定义，并让它只返回结构化结论和短理由。

### 5.1 Planner Prompt

**调用时机：** 用户提交新请求，5 张空间帧准备好后。  
**输入：** 用户原句、relation catalog 的紧凑版本、5 张带 view id 的原始图片、JSON schema。  
**输出：** `PlanV2`。

Tentative system prompt：

```text
You are the planning component of a camera-based attention assistant.
Convert the user's request into a small executable watch plan using only the
provided relation catalog. Do not invent relation IDs or visual capabilities.

The five images are different spatial views, not a temporal video.
First identify relevant entities and assign stable IDs within each view.
Then choose at most three watch rules. Bind every object-directed relation to
a concrete target entity. Use the simplest rule that expresses the request.

If the request cannot be represented or an entity is not visible, report that
explicitly in missing_capabilities or assumptions. Return only schema-valid JSON.
```

动态 user payload：

```text
USER_REQUEST: 帮我看有没有人开始用我的电脑
RELATION_CATALOG_VERSION: 2.2
RELATION_CATALOG: <compact JSON>

IMAGE view_1, camera_role=planning, pan=-60
<image>
...
IMAGE view_5, camera_role=planning, pan=+60
<image>
```

建议输出：

```json
{
  "schema_version": "2.0",
  "normalized_request": "发现有人开始操作用户的电脑",
  "entities": [
    {"entity_id": "laptop_1", "label": "laptop", "view_id": "view_3", "box": [0.42, 0.30, 0.75, 0.72]}
  ],
  "best_view_id": "view_3",
  "watch_rules": [
    {
      "rule_id": "rule_1",
      "label": "someone starts using the laptop",
      "then": [
        {"relation_id": 8, "subject": "person:any", "target_entity_id": "laptop_1"},
        {"relation_id": 9, "subject": "same_as_previous", "target_entity_id": "laptop_1"}
      ],
      "within_s": 4.0,
      "persist_frames": 2,
      "cooldown_s": 15
    }
  ],
  "assumptions": [],
  "missing_capabilities": []
}
```

### 5.2 Plan Repair Prompt

只有 validator 拒绝第一次输出时调用一次：

```text
Your previous plan was not executable.
Validation errors:
- rule_1 condition 2 requires target_entity_id
- relation_id 14 does not exist

Repair only these errors. Keep the user's intent and visible entity IDs.
Return only a complete schema-valid PlanV2 JSON object.
```

第二次仍不合法时，不安装 bad plan：保留上一份 valid plan，或进入 safe fallback 并在 UI 显示错误。

### 5.3 Event Confirm + Feedback Prompt

**调用时机：** 本地 CV matcher 通过 relation、entity binding、persist、onset、cooldown 和画质 gate 后。  
**输入：** 原始用户请求、当前 rule、CV facts、5 张时间帧。  
**输出：** `EventDecision`。确认和一行反馈合并为一次 API call。

```text
You are a strict visual event verifier.
The five images are ordered temporal evidence from the same camera view.
Decide whether the requested event actually occurred and whether the subject
and target match the rule. CV facts are candidate evidence, not ground truth.

Return confirmed=false when evidence is ambiguous, target identity is wrong,
the required order is reversed, or the event is visible in only one noisy frame.
Do not infer actions outside the images. The feedback must be one short Chinese
sentence suitable for printing directly to the user. Return only JSON.
```

Payload outline：

```text
USER_REQUEST: 帮我看有没有人开始用我的电脑
RULE: <rule_1 JSON>
CV_FACTS: <bound RelationFact JSON array>

IMAGE event_t_minus_1_0s
<image>
IMAGE event_t_minus_0_5s
<image>
IMAGE event_t_0_onset
<image>
IMAGE event_t_plus_0_5s
<image>
IMAGE event_t_plus_1_0s
<image>
```

输出 schema：

```json
{
  "confirmed": true,
  "confidence": 0.91,
  "matched_rule_id": "rule_1",
  "subject_id": "person_1",
  "target_entity_id": "laptop_1",
  "evidence_frame_ids": ["event_t_0_onset", "event_t_plus_0_5s"],
  "reason": "同一人靠近并连续触碰指定电脑",
  "feedback": "我看到有人开始使用你的电脑了。"
}
```

### 5.4 Audit Prompt（非 MVP）

只有“画面里持续有人，但所有关系长时间为 false”时低频抽样，询问是否存在 vocabulary 未覆盖的重要事件。它用于研究 relation coverage，不参与第一版实时链路。

---

## 6. 调用表

| 阶段 | Trigger | 本地输入 | API 输入 | 结构化输出 | 下一步 |
|---|---|---|---|---|---|
| User input | UI submit / CLI text | 用户原句 | 无 | request id | 开始取 planning views |
| Planning | 5 个 view ready | request + 5 raw images + relation catalog | Gemini 1 call，5 image parts | `PlanV2` | validator |
| Validation | Planner 返回 | PlanV2 + evaluator registry | 无 | valid plan / errors | install 或 repair once |
| CV watch | valid plan installed | webcam + 默认 1 Hz entities/tracks | 无 | `RelationFact[]` | matcher |
| Candidate | rule 从 false→true 且 persist 达标 | facts + rule + ring buffer | 无 | `EventCandidate` | 等待后两张时间帧 |
| Confirm | 5 event frames ready | request + rule + facts + 5 raw images | Gemini 1 call，5 image parts | `EventDecision` | confirmed gate |
| Feedback | `confirmed=true` | decision.feedback | 无 | 一行 stdout | cooldown，继续 watching |
| Reject | `confirmed=false` | decision + reason | 无 | debug log，不通知用户 | 继续 watching |

反馈动作在本阶段固定为：

```text
[FEEDBACK] 我看到有人开始使用你的电脑了。
```

不调用 `robot/`、CoreS3、LED、speaker 或 motion clip。

---

## 7. Trigger 机制

```mermaid
flowchart TD
    A["CV produces bound RelationFacts at configured rate"] --> B{"Rule and target binding match?"}
    B -- No --> A
    B -- Yes --> C{"Persist for N frames?"}
    C -- No --> A
    C -- Yes --> D{"False → true onset?"}
    D -- No --> A
    D -- Yes --> E{"Rule cooldown clear?"}
    E -- No --> A
    E -- Yes --> F{"Camera settled and frame quality OK?"}
    F -- No --> A
    F -- Yes --> G["Create EventCandidate"]
    G --> H["Collect 5 temporal frames around onset"]
    H --> I["Gemini Event Confirm"]
    I --> J{"confirmed?"}
    J -- No --> A
    J -- Yes --> K["Print one feedback line"]
    K --> L["Start rule + subject + target cooldown"]
    L --> A
```

Candidate key 应该是 `(rule_id, subject_id, target_entity_id)`，而不是只有 relation id。这样不同人、不同物体之间不会共享错误 cooldown。

---

## 8. Relation Catalog：JSON single source of truth

新增 `schemas/relation_catalog.v2.json`。每个 relation 包含：

```json
{
  "id": 9,
  "key": "hands_on",
  "name": "hands-on / manipulating",
  "subject_type": "person",
  "target_type": ["object"],
  "target_required": true,
  "variants": ["touch", "manipulate", "offer"],
  "evidence_chain": [
    "detect and track subject person",
    "detect and track target object",
    "estimate left and right wrist landmarks",
    "test wrist inside or near target box",
    "require the condition for at least 1.0 seconds"
  ],
  "negative_cases": [
    "wrist overlaps a different object",
    "single-frame accidental overlap",
    "target is occluded and identity is uncertain"
  ],
  "evaluator": "hands_on_v2"
}
```

JSON 定义“关系是什么意思、需要什么证据”；Python evaluator 真正执行几何计算。启动时 registry 检查 catalog 中每个可用 relation 都有实现，防止 Prompt 宣称能检测但代码里没有 evaluator。

---

## 9. Proposal 的代码改动

### 9.1 建议目录

```text
schemas/
  relation_catalog.v2.json       # 11 种关系唯一语义来源
  plan_v2.py                     # Pydantic PlanV2
  relation_fact.py               # Pydantic RelationFact / EventCandidate
  event_decision.py              # Pydantic EventDecision

planning/
  prompt_builder.py              # compact catalog + multi-image payload
  validator.py                   # schema + semantic + capability validation
  compiler.py                    # PlanV2 -> executable rules
  providers/
    base.py                      # Planner/Judge provider interface
    gemini.py                    # Gemini implementation

perception/
  detector.py                    # detector interface and YOLO adapter
  tracker.py                     # ByteTrack entity IDs
  pose.py                        # MediaPipe face/body adapter
  relation_registry.py           # catalog key -> evaluator
  evaluators/                    # one relation evaluator per file/group

events/
  matcher.py                     # all/any/not/then + entity binding
  frame_buffer.py                # raw frame ring buffer
  candidate.py                   # onset/persist/cooldown/quality gate
  gemini_confirm.py              # five temporal images -> EventDecision

feedback/
  base.py
  console.py                     # MVP: print one line only
  robot.py                       # future; this阶段不调用
```

### 9.2 分阶段修改

| Phase | 改动 | 完成标准 |
|---:|---|---|
| 1 | Relation catalog、Pydantic schemas、validator、unit tests | 非法 relation、缺 target、反向 then 都会被拒绝 |
| 2 | Gemini provider + 5 张独立 planning images | 不再依赖 contact sheet；能稳定返回 PlanV2 |
| 3 | Tracker + bound RelationFact；旧 truth vector 暂时兼容 | rule 能绑定同一 person 和指定 object |
| 4 | Candidate matcher + 5-frame ring buffer | onset、persist、sequence、cooldown 均有单测 |
| 5 | Gemini event confirm 接到 finding 前面 | 未确认事件不会进入 feedback |
| 6 | `--robot none --feedback console` | 普通 laptop + webcam 可以跑完整链路 |
| 7 | 清理旧 Anthropic production path | 已完成；MVP 只需要 Gemini key |
| 8 | 真实机器人 adapter | 单独验收，不影响 webcam-only runner |

### 9.3 必须一起修的现有问题

- Planner invalid 会重试一次；仍 invalid 时不会 install。
- `_focus_ok` 目前没有对所有 object-directed relations 做严格 target binding。
- `then` 已改为严格顺序；反向或同时发生均为 false。
- Planner 后台线程带 request generation id，STOP 或新请求后丢弃旧结果。
- CV candidate 不能在 S6/S7 继续消耗一个用户还没看到的 cooldown。
- Gemini confirm 已发生在 finding/S7 之前。
- `duration_s` 要真正终止或重新规划，而不是只存在 JSON 中。
- 退出前要 flush/join 正在 finalize 的 event，避免最后一条记录丢失。

### 9.4 依赖建议

第一版需要：

```text
google-genai
python-dotenv
pydantic>=2
opencv-contrib-python
numpy
mediapipe
ultralytics
pytest
```

YOLO 自带 ByteTrack 接口，第一版不需要额外安装 DeepSORT。也先不要加入 SAM、CLIP、action-recognition、depth estimation；只有真实测试显示某个 relation 无法达到精度时再加。

---

## 10. 本机 webcam 的真实 E2E 怎么跑

### 10.1 当前马上可跑：Gemini 视频 smoke test

这只能验证“Gemini 看视频 + 用户 trigger + JSON 返回”，**不是完整 CV→candidate→5 frame confirm pipeline**。

```bash
cd /Users/zhangjianan/Desktop/HRI/potato-sidekick

python3 -m venv .venv
source .venv/bin/activate
pip install -r requirements.txt

cp .env.example .env
# 编辑 .env，填入 GEMINI_API_KEY

python3 planning/gemini_video_trigger.py /absolute/path/to/test.mp4 \
  "当有人开始使用我的电脑时告诉我"
```

预期输出：

```json
{
  "feedback_trigger": true,
  "confidence": 0.91,
  "evidence_timestamps": ["00:04"],
  "feedback": "我看到有人开始使用你的电脑了。",
  "reason": "视频中有人靠近并操作电脑"
}
```

### 10.2 重构完成后的目标 E2E 命令

先检查 webcam index：

```bash
python3 noticebot_loop.py --list-cams
```

运行电脑-only 模式：

```bash
python3 noticebot_loop.py \
  --cam 0 \
  --robot none \
  --input text \
  --feedback console \
  --detector yolo \
  --cv-hz 1 \
  --planning-view fixed \
  --serve
```

浏览器打开 `http://localhost:8000`，在 context 输入：

```text
帮我看有没有人开始使用我的电脑
```

真实运行顺序：

1. webcam 持续采集，Web UI 显示 raw preview。
2. 用户提交文字后，程序取得 5 张 planning spatial frames。
3. 一次 Gemini call 返回 entities、best view 和 watch rules。
4. validator 通过后才 install plan；UI 显示人类可读的 rule。
5. Grounding DINO + MediaPipe 默认约 1 Hz 输出 bound RelationFacts；需要更低延迟时切换 `--detector yoloworld`。
6. 当同一个人满足指定电脑的 rule，candidate gate 记录 onset。
7. ring buffer 取 onset 前两张，再等待后两张，共 5 张时间帧。
8. 一次 Gemini call 确认事件并返回 `EventDecision`。
9. 若 `confirmed=true`，终端输出：

   ```text
   [FEEDBACK] 我看到有人开始使用你的电脑了。
   ```

10. 系统进入该 `(rule, person, laptop)` 的 cooldown，然后继续观察。

### 10.3 推荐的第一次人工 E2E 场景

固定 webcam 对着桌面，保证一个人和 laptop 都完整入镜：

1. 先保持 3 秒无人触碰电脑，建立 negative baseline。
2. 一个人进入画面，走近 laptop。
3. 手放到键盘/触控板并操作 2 秒。
4. 期望只产生一个 candidate、一个 Gemini confirm、一个 feedback line。
5. 立即重复动作时应被 cooldown 抑制。
6. 手碰旁边的 cup 不应触发 laptop rule。
7. 把“先操作、再靠近”倒序表演，不应满足 `approach then hands-on`。

保存以下调试产物，但不保存 Key：

```text
runs/<run_id>/request.json
runs/<run_id>/plan.json
runs/<run_id>/relation_facts.jsonl
runs/<run_id>/candidates.jsonl
runs/<run_id>/decisions.jsonl
runs/<run_id>/events/<event_id>/frame_01.jpg ... frame_05.jpg
```

---

## 11. MVP 验收标准

- 只配置 `GEMINI_API_KEY` 就能运行 production VLM path。
- 主入口不连接机器人硬件也能启动。
- Planner 和 Judge 都使用 5 张独立图片，不依赖 contact sheet 或整段视频。
- CV 默认以约 1 Hz 运行，但 camera/ring buffer 保持连续帧；YOLO-World 可配置为 4 Hz。
- 每个 object-directed relation 都带正确 `target_entity_id`。
- 非法 Plan、反向 `then`、错误 target、单帧闪烁都不会产生反馈。
- Gemini 返回 `confirmed=false` 时用户不会收到反馈。
- 每个已确认事件只打印一行；没有 motion、LED、CoreS3 或声音副作用。
- 无 API key 的 unit/integration tests 使用 fake provider 并完全可重复。

## 12. 最终建议

先实现 Phase 1–6，形成一个可以在 laptop webcam 上反复测试的闭环，再接真实舵机和 CoreS3。最重要的边界不是换一个模型，而是把 **Plan schema、entity binding、candidate trigger、Gemini confirm、feedback adapter** 五个接口固定下来；这些接口稳定以后，Gemini 型号、detector 和机器人硬件都可以独立替换。

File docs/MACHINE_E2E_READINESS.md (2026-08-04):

# NoticeBot 真机 E2E Readiness 与到货测试清单

> 更新：2026-08-03  
> 分支：`sonen/modification`  
> 目标机器：3× SCS0009、FE-URT2、OV4688 head camera、M5Stack CoreS3、Mac laptop  
> 本文只讨论真机路径；Mac 内置 webcam 不是 blocker。

## 结论

软件路径已经具备一条命令完成目标 E2E 的接线；是否 GO 只剩真机到货后必须实际确认的电气、校准、串口、相机和机械安全：

```text
用户请求 → Gemini 五视角 Plan → 真机 CV watch → 五时间帧 Confirm
→ 只输出一行 feedback
```

当前大致状态：

| 层 | 状态 | 证据 / 缺口 |
|---|---|---|
| CV 模型本机加载 | 🟢 | Grounding DINO + MediaPipe、YOLO-World + MediaPipe 真实图片测试通过 |
| YOLO-World 接口 | 🟢 | 连续推理约 94–132 ms，动态 vocabulary 可用 |
| Gemini API | 🟢 | Flash-Lite、minimal thinking、low resolution、priority tier 真实调用通过 |
| SessionFlow | 🟢 | 逻辑测试全部通过 |
| 真机舵机/CoreS3/camera | ⚪ | 等机器到货才能验证 |
| 当前 `.venv` 硬件依赖 | 🟢 | full `requirements.txt` 已安装，`pip check` 通过 |
| 当前 production Planner | 🟢 | 主循环已调用 Gemini structured output |
| 五张独立 Planning 图片 | 🟢 | sweep 独立图片送 Gemini；grid 只作本地 debug |
| Candidate 五帧 Confirm | 🟢 | `t-1,-.5,0,+.5,+1` 已接在 finding 之前 |
| Plain-line feedback | 🟢 | 默认 `--feedback console`；不会进入 S7/CoreS3 feedback |

因此，明天正确目标是：**先得到每一层的 GO，再进行受控组合**。不要把所有未知量一次接上。

---

## P0：机器到之前的软件准备（已完成）

### P0.1 安装完整硬件运行依赖

当前 `.venv` 已补齐：

```text
scservo_sdk: OK
serial: OK
faster_whisper: OK
google.genai: OK
ultralytics: OK
mediapipe: OK
cv2: OK
```

其中：

- `feetech-servo-sdk`：舵机总线必须。
- `pyserial`：CoreS3 必须。
- `faster-whisper`：如果第一轮使用 Web UI 文字输入，可以暂缓。

安装命令：

```bash
cd /Users/zhangjianan/Desktop/HRI/potato-sidekick
source .venv/bin/activate
pip install -r requirements.txt
pip check
```

完成后至少确认：

```bash
python -c "import scservo_sdk, serial, google.genai, cv2, mediapipe"
```

### P0.2 明确明天测试的是哪条 VLM 路径

现在 production 统一为 Gemini；whole-video 脚本只作独立 smoke：

| 路径 | 当前状态 | 用途 |
|---|---|---|
| Gemini video trigger | 独立脚本、真实 API 已通过 | whole-video API smoke |
| Gemini 五图 Planner + 五图 Confirm | 已接 production 主循环 | 明天真机目标路径 |

如果明天主要测试真机动作和传感链路，建议第一轮设置：

```bash
python noticebot_loop.py ... --offline
```

这样先排除云端模型不确定性；`--offline` 现在同时覆盖 Planner 和 Judge。

真实语义 Planning 只需要 `.env` 中有效的 `GEMINI_API_KEY`。

### P0.3 增加安全的 feedback 模式

之前已经决定此阶段反馈只输出：

```text
[FEEDBACK] 我看到有人开始使用你的电脑了。
```

但当前主循环中，CV finding 会发出 `finding` event，并进入：

```text
S7a found motion → S7b beckon loop
```

这与当前目标不一致，也是首次上电的机械风险。真机自动 E2E 前需要一个明确开关：

```text
--feedback console
```

该模式现已实现，并且是默认值：

- 可以记录 event/feed。
- 可以在终端打印一行反馈。
- 不请求 S7a/S7b。
- 不发 CoreS3 sound/LED feedback。
- 人工按 `7` 测动作仍然保留，便于单独验收机械动作。

### P0.4 准备物理急停

软件 STOP 会回到 S1，但不是电气急停，也不一定立即解除 torque。

到货测试桌上必须有：

- 可以立即断开的独立 5–6 V servo power。
- 一个人盯着 cable loom 和机械干涉。
- 终端保持可输入 `r`/退出。
- 第一次动作从 center、小幅 jog 开始，不能直接跑完整 sweep。

---

## P1：到货后先通物理与电气

### 1. 不上电检查

- 确认 servo IDs 预期为 pan=1、tilt=2、nod=3。
- 确认 FE-URT2 signal slider 为 5 V，不是 3.3 V。
- 确认 servo rail 使用独立 5–6 V，绝不能接 9 V/12 V。
- 确认 USB 和外部 servo power 同时连接的走线正确。
- 手动轻微活动机构，确认没有包装、螺丝、线束卡住。
- 特别检查 pan 轴 camera cable loom；这是现有设计的机械限位来源。
- 确认 horn 没有跨 0/1023 seam。

### 2. 只开逻辑/总线，不做大动作

预期系统可能看到两个 `/dev/cu.usbmodem*`：servo adapter 和 CoreS3。不能靠端口名字猜。

```bash
python robot/tools/check_bus.py
```

Pass：

- ID 1/2/3 都能 ping。
- model id 合理。
- voltage ≥5.0 V；最好 ≥5.5 V。
- temperature 合理。
- 没有位置读数跳过 1023→0。

如果只读到约 4.3 V，说明可能在吃 USB back-feed：能 ping 不代表能安全运动。

### 3. 校准不能直接相信旧数值

当前 `robot/calibration.py` 的 `UNCALIBRATED` 是空集，因此 preflight 会显示 calibrated；但 nod 的注释仍明确写着首次真机需要确认方向。

必须逐轴验证：

1. center 是否真的是机械中位。
2. 正方向是否和 Blender/render 一致。
3. limit 是否在碰撞前留出余量。
4. pan cable 在 ±60° sweep 时是否被拉紧。
5. nod clip 是抬头还是低头，确认 `INVERT["nod"]`。

不要因为 preflight 显示 GO 就跳过这一步。

---

## P2：逐个通执行器和 CoreS3

### 1. 舵机逐轴

顺序：

```text
pan 小幅 jog → tilt 小幅 jog → nod 小幅 jog → center → 单个 clip → 全状态 clips
```

每一步观察：

- 实际方向。
- 是否撞限位。
- 电压是否掉落。
- servo 温度和异常噪声。
- pan camera cable 是否扭转。

单 clip 从静态/小动作开始，S4 sweep 和 S7 beckon 最后测。

### 2. CoreS3

必须验证协议握手：

```text
laptop → EVT PING
CoreS3 → IN PONG cores3_sidekick v2
```

然后逐项测：

- PTT_DOWN / PTT_UP。
- OK。
- STOP。
- BODYTAP。
- 9 个 UI screens。
- LED hue / level。
- speaker volume / sfx。

注意：`session/cores3_link.py` 底部的 standalone demo 仍发送 `ARMED/WATCH/FOUND/KEEP/STEP` 等已删除旧命令，因此它现在不能作为可信验收脚本。应先更新为 v2 命令或直接通过主循环/一个新的协议 smoke test 验证。

### 3. 两个串口同时存在

必须验证：

- `open_bus()` 找到 servo adapter。
- `find_cores3(exclude=(servo_port,))` 找到 CoreS3。
- 重新插拔或换 USB 口后仍能重新发现。
- CoreS3 PING 不会误发给 servo adapter。

---

## P3：通头部相机与 sweep

Mac 内置 webcam 不重要，但 head camera 必须验证。

```bash
python noticebot_loop.py --list-cams
```

Pass：

- 找到 OV4688 对应 index。
- 能取得非 square、预期分辨率的稳定画面。
- 机械运动时 USB cable 不掉线。
- S4 的 5 个 settled station 都捕获到 raw frame。
- station 间距约 30°，覆盖 −60°…+60°。
- frame 只在 `settled_ms > SETTLE_MS` 时进入 Planning。
- 每张图对应的 pan angle 正确，没有“已经到了下一角度却标成上一角度”。

建议同时保存并人工检查：

```text
session_feed/sweeps/<timestamp>/panorama.jpg
session_feed/sweeps/<timestamp>/pan_*.jpg
session_feed/sweeps/<timestamp>/plan.json
```

必须确认 overlay 只用于 debug；送给 VLM 的 planning 图必须是 raw frame。

---

## P4：通真机 CV

### 默认路径

```text
Grounding DINO + MediaPipe，约 1 Hz
```

运行时重点不是追求高 FPS，而是检查：

- detector vocabulary 能被 Plan 更新。
- person 和目标物在真实相机距离下可见。
- face/pose 在机器人实际 FOV 和高度下稳定。
- 运动停止后 CV 才处理图像。
- CV 推理不会让 servo/CoreS3 heartbeat 饿死。

### 低延迟备选

```bash
--detector yoloworld --cv-hz 4
```

YOLO-World 本机静态图已经通过，但真机还要验证：

- 目标 vocabulary 在实验环境中的召回率。
- 多词标签，例如 `cell phone`、`robot arm`。
- `set_vocab()` 在重新 Planning 后真的更新。
- 模型切换/首次加载不会发生在参与者等待期间。

### 关系触发必须逐类测

不要一开始测 11 种。明天先选三个最容易观察的：

1. ID 3 eye-contact：只需要 face。
2. ID 9 hands-on：person pose + 明确物体。
3. ID 10 gathering：person count change。

然后再测：

- ID 1 gaze-at。
- ID 4 pointing。
- ID 7 approach/depart。
- ID 11 handoff。

已知语义风险仍存在：当前 truth vector 是全局 bool，object binding 对 ID 8/9/11 等还不严格；`then` 可能退化成 AND。它们在修复前不能作为最终精度验收。

---

## P5：通 Planning

### 当前 production 路径

```text
5 个独立 sweep frames → Gemini structured output → validated watch spec
```

要检查：

- `seen/detect/focus/boxes/watch` 都存在。
- richest pan 与人工判断大致一致。
- Planner 返回 validation violations 时不能静默安装坏 spec。
- STOP 或新的 request 出现后，旧 planner thread 的结果不能覆盖新状态。

后两项目前是已知代码风险，不应跳过。

Planner 结果带 request generation；STOP 或新请求后，迟到结果会被丢弃。第一次 invalid 会重试一次，仍 invalid 则拒绝安装。

---

## P6：通 Candidate → Confirm → Feedback

目标链路：

```text
CV RelationFacts
→ entity/target match
→ persist
→ false→true onset
→ strict sequence
→ cooldown
→ 收集 onset 前后 5 张时间帧
→ Gemini Confirm
→ confirmed=true
→ console feedback
```

当前已经通：

- strict `then`，不会退化成 AND。
- raw-frame JPEG ring buffer。
- 5 张时间图片的 Gemini Confirm。
- Confirm 位于 finding/S7 之前。
- `--feedback console` adapter。
- gaze/point/lean/hands-on/approach/handoff 的 target-label gate。

仍需后续升级的是跨多人/同类多物体的稳定 instance ID；明天单人、单目标 E2E 不受此限制。

因此明天可以手动用 `f` 验证 finding/story plumbing，但不能把它当成目标自动 E2E 已通过。

---

## P7：并发、恢复与长时间稳定性

各组件单独通过后还要通这些边界：

| 场景 | 预期行为 |
|---|---|
| Gemini 请求进行中按 STOP | 立即取消当前 task；迟到结果不能重新安装 |
| Planning 中 CoreS3 STOP | 回 S1，清空 sweep/spec |
| Camera 短暂掉线 | 不运动到错误角度，不生成 candidate，清晰报错 |
| CV 推理异常 | motion/UI 继续，研究者仍可人工触发 |
| Gemini timeout/invalid JSON | 不安装坏 Plan，不进入 S7 |
| Servo 电压过低 | preflight NO-GO，不开始 session |
| CoreS3 断开 | 主程序不中断 servo safety；日志明确 |
| 同一事件持续很久 | 只触发一次，必须 break/re-form 且 cooldown 结束 |
| 多人/多物体 | subject/target 不串线 |
| 程序退出时 story 尚在 finalize | flush/join，最后事件不丢失 |

最后做至少 20–30 分钟 soak test，观察：

- camera 是否持续有帧。
- 串口是否断连。
- servo 温度。
- 内存是否持续增长。
- CV/Gemini thread 是否堆积。
- feed/sweep 文件是否落盘完整。

---

## 明天推荐执行顺序

| 顺序 | 测试 | 允许动作 | GO 条件 |
|---:|---|---|---|
| 0 | 视觉/接线检查 | 不上电 | 无干涉、供电明确 |
| 1 | Servo bus | 只读/ping | 3 IDs、正确电压温度 |
| 2 | Calibration | 小幅单轴 | center、方向、limits 正确 |
| 3 | Motion clips | 单 clip | 无碰撞、无掉压 |
| 4 | CoreS3 | UI/input only | v2 PING 和全部输入通过 |
| 5 | Head camera | camera only | 正确 index、稳定画面 |
| 6 | S4 sweep | 慢速受控 | 5 station raw frames 正确 |
| 7 | CV | 不自动触发动作 | person/target/pose 可见 |
| 8 | Offline state E2E | console/manual finding | S1→S7→S5 可控 |
| 9 | Cloud Planning | 先旧路径或 Gemini 单测 | valid Plan、正确 richest view |
| 10 | 自动 Trigger | console feedback only | 一次正确 trigger，无误动作 |
| 11 | Soak | 安全模式 | 20–30 分钟稳定 |

---

## 最小真机命令路线

依赖完成后：

```bash
cd /Users/zhangjianan/Desktop/HRI/potato-sidekick
source .venv/bin/activate

# 1. 找 head camera
python noticebot_loop.py --list-cams

# 2. 总线和 calibration/clips/camera 总检查
python robot/tools/preflight.py --cam <HEAD_CAM_INDEX>

# 3. 第一轮排除 STT 和云端 Planner，使用 Web UI 文字输入
python noticebot_loop.py \
  --cam <HEAD_CAM_INDEX> \
  --cores3 \
  --no-stt \
  --detector gdino \
  --cv-hz 1 \
  --offline \
  --serve

# 4. Offline GO 后，运行真实 Gemini E2E
python noticebot_loop.py \
  --cam <HEAD_CAM_INDEX> \
  --cores3 \
  --no-stt \
  --detector gdino \
  --cv-hz 1 \
  --feedback console \
  --serve
```

默认 console feedback 不会自动请求 S7；只有显式传 `--feedback robot` 才允许确认事件进入机器人反馈动作。

---

## 明天的最终 GO / NO-GO

### Hardware bring-up GO

- 三个 servo ping、voltage、temperature 正常。
- pan/tilt/nod center、方向、limits 人工确认。
- CoreS3 v2 PING、PTT、OK、STOP、BODYTAP 正常。
- OV4688 在完整 sweep 中不掉线。
- preflight 显示 GO。

### Software-on-machine GO

- S1–S8 clips 单独运行安全。
- S4 得到 5 个正确角度的 raw frame。
- Grounding DINO 或 YOLO-World 能在真机视角检测 person 和目标物。
- MediaPipe 至少能稳定输出 face/pose。
- offline Plan 能进入 S5，STOP 能可靠清空任务。
- 运行 20–30 分钟无串口/camera/thread 堆积问题。

### Target architecture E2E GO

只有以下全部完成才可以宣布：

- Gemini 五张独立空间图片 Planner 已进入主循环。
- PlanV2 validation 失败时不会 install。
- CV 输出 bound RelationFacts。
- strict sequence、onset、persist、cooldown 通过测试。
- 五张时间图片 Gemini Confirm 位于 finding 前。
- `confirmed=false` 不反馈。
- `confirmed=true` 只输出一行 feedback。
- 默认不会触发 S7/LED/sound 等未授权动作。

## 当前判断

软件已经整理到**接上真机即可分层 E2E**：Gemini Planner、独立空间图片、CV candidate、五时间帧 Confirm 和 console feedback 已贯通并分别测试。剩余未知量是必须依赖实物确认的供电、calibration、双串口、head-camera index 和线束机械安全。

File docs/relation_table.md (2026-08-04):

# Relation Table v2 — a VLM-composable vocabulary of socially meaningful relations
*(all computable from MediaPipe + an object detector; paper-bound file, keep in English)*

**v2 (2026-06-10):** added row 11 (turn-taking / control handoff) — the single strongest
finding of the v1 preliminary study's plan-time probe (14 mentions; 100% of pair-prog
runs). Notably, it corresponds to a taxonomy channel (interaction regulation — Ekman &
Friesen's "regulators") that v1 had left unsampled: the probe found a *channel* gap, not
a random omission. One row changed ⇒ the v1→v2 study comparison isolates its effect.

Architecture (2026-06-10, after supervisor discussion): **VLM-first**.
Context (a typed prompt for now; other robot-interaction modalities later) + the current
frame → the VLM understands the situation → selects, from the FIXED vocabulary below,
which relation or which CONJUNCTION of relations (e.g. 3+5, 2+7) is worth recording in
THIS context → CV then watches for a period, evaluating **T/F for all rows 1–10 every
frame** (the per-frame truth vector is itself logged data) and recording the moments when
the chosen conjunction is satisfied.

Design properties:
- The VLM does NOT run per frame: it re-plans only on context change, user input, or a
  periodic recheck. The cheap-runtime cost structure is preserved.
- The vocabulary is fixed and literature-grounded — the contribution is a
  **theory-grounded perceptual vocabulary** for VLM program synthesis (related work:
  ViperGPT, VisProg, Code-as-Policies, where the vocabulary is API calls instead).
- Only three perceptual primitives, all already in the repo: **F** = FaceLandmarker
  (head pose / gaze ray), **P** = PoseLandmarker (33 keypoints, multi-person),
  **D** = object detector (object slots).

## The vocabulary (rows 1–10)

| # | Relation | Geometric trigger (T/F test) | Prim. | Theoretical anchor | Triggerability | Status |
|---|---|---|---|---|---|---|
| 1 | **gazing-at** (person → object) | head-orientation 2D ray hits object box, ±12° | F+D | ？ | high | ✅ gaze.py |
| 2 | **joint-attention** (people → shared target) | ≥2 gaze rays converge in front of both (t>0); stronger when the convergence point falls in an object box | F(+D) | ？ | med | ✅ gaze.py |
| 3 | **eye-contact** (person → robot) | 3D face-forward within ±12° of the face→camera direction | F |  (equilibrium theory); Kendon 1967; Media Equation | high | ✅ gaze.py |
| 4 | **pointing / reaching** (person → object or person) | elbow→wrist ray, emitted only when the arm is extended (elbow ≥140°); ray hits target box | P+D | Proto-declarative pointing — Bates et al. 1975; Kita 2003 | high | ✅ gaze.py |
| 5 | **proxemic zone** (person ↔ person) | pelvis-centre distance normalised by mean shoulder width → intimate / personal / social / public; shoulder width as the scale proxy (no depth needed) | P | **Proxemics — Hall 1966** (The Hidden Dimension) | high | ⬜ |
| 6 | **F-formation / facing** (person ↔ person) | shoulder-line normals (body orientations) point toward each other and their o-spaces overlap | P | **Kendon 1990** (F-formations); CV precedent: Cristani et al. 2011 | med | ⬜ |
| 7 | **approach / depart** (transition) | normalised person↔target (object/person/camera) distance decreases/increases monotonically beyond a threshold within a ~3 s window | P(+D) | ？ | med | ⬜ |
| 8 | **lean-in / hover-over** (engagement posture) | torso pitch (mid-shoulder→mid-hip vs vertical) tilted >15° toward an object/desk, sustained | P(+D) | Postural immediacy / lean | med | ⬜ |
| 9 | **hands-on / manipulating** (person–object contact) | wrist keypoint inside an object box (or within 0.1×diag of its edge) sustained ≥1 s; wrist extended toward another person with object in hand = the *offering* variant | P+D | ？ | high | ⬜ |
| 10 | **gathering / co-presence** (group state) | person count crosses a threshold (0→1, 1→2, ≥3 forming a cluster: pairwise distances < social zone) | P or D | Gatherings / face engagements — **Goffman 1963** (Behavior in Public Places) | high | ⬜ |
| 11 | **turn-taking / control handoff** (person ↔ person, via artifact) | the person whose wrist is inside / nearest the shared artifact's box "holds control" (sustained ≥1 s); a HANDOFF = the controlling person changes | P+D | Turn-taking | med (needs cross-frame state, like row 7) | ⬜ |

✅ = implemented & unit-tested (gaze.py) ⬜ = to build (5/9/10 easy geometry; 6/7/8 medium; 7 needs cross-frame state)

## Technical grounding — every trigger is an ESTABLISHED vision task

The geometric triggers are not inventions: each row maps onto a CV task with its own
literature and benchmarks, computed from primitives that are themselves standard
(MediaPipe framework — Lugaresi et al. 2019; FaceMesh — Kartynnik et al. 2019;
BlazePose — Bazarevsky et al. 2020). This is the *technical* twin of the theory column.

| Row | Established CV task | Precedent |
|---|---|---|
| 1 gazing-at | head-pose estimation + gaze following | Murphy-Chutorian & Trivedi 2009 (TPAMI survey); Recasens et al., NeurIPS 2015 ("Where are they looking?") |
| 2 joint-attention | shared-attention inference in video | Fan et al., CVPR 2018 |
| 3 eye-contact | eye-contact / attended-target detection | Chong et al., CVPR 2020; Ye et al. 2015 |
| 4 pointing | pointing-gesture recognition (HRI) | Nickel & Stiefelhagen 2007, Image Vis. Comput. |
| 5 proxemic zone | proxemics recognition from images | Yang et al., CVPR 2012 |
| 6 F-formation | F-formation detection | Cristani et al., BMVC 2011; Setti et al. 2015 (GCFF) |
| 7 approach/depart | person tracking / trajectory analysis | standard multi-object tracking (mature) |
| 8 lean-in | keypoint-based posture analysis | standard pose-landmark geometry |
| 9 hands-on | hand–object contact detection | Shan et al., CVPR 2020 (100DOH) |
| 10 gathering | person detection / group detection | mature; group: Cristani et al. 2011 |
| 11 turn-taking | hand–object contact (per person) + identity over time | composition of Shan et al. 2020 + standard tracking |

**The third leg is empirical and ours to produce:** a detectability mini-study on the
actual rig — the point being that **a small, low-cost camera suffices** for all ten
relations (frame rate and resolution are properties of the current module, not of the
approach, and may improve with hardware). Per relation, N staged positive and N staged
negative trials at room distances → hit rate / false-alarm rate, reported as a "measured
reliability" column. The protocol and recording sheet live in TEST_PLAN_system.md (section 2). Failure conditions (side-on pointing,
distance limits) go into the paper's limitations — measured, not guessed.

## Why these ten — selection rationale (the claim, stated carefully)

We do NOT claim these ten rows are *sufficient* for all scenarios (unprovable for an open
set). The defensible claim has two parts:

**1. Channel coverage (structural argument).** Nonverbal-communication research organises
social behaviour into established channels — gaze/oculesics, gesture/deixis, proxemics,
posture/kinesics, object manipulation, and group spatial organisation (Knapp & Hall,
*Nonverbal Communication in Human Interaction*; Vinciarelli, Pantic & Bourlard 2009,
*Social Signal Processing: Survey of an Emerging Domain*, Image and Vision Computing —
their taxonomy of behavioural cue classes). The vocabulary samples **every channel of
that taxonomy that is detectable from vision alone** with our three primitives (no audio,
no touch, no physiology):

| Channel (taxonomy) | Rows |
|---|---|
| gaze / oculesics | 1 gazing-at, 2 joint-attention, 3 eye-contact |
| gesture / deixis | 4 pointing |
| proxemics (static / dynamic) | 5 zones, 7 approach-depart |
| posture / kinesics | 8 lean-in |
| object-directed action | 9 hands-on |
| group spatial organisation | 6 F-formation, 10 gathering |
| interaction regulation (v2) | 11 turn-taking / control handoff |

So the selection is per-channel sampling under a detectability constraint, not an ad-hoc
list. Each row additionally carries its own grounding (the table above).

**2. Coverage as an empirical question (the probe).** Sufficiency is delegated to data,
at three complementary moments:

- **Plan-time probe (implemented; what the preliminary study measured).** The planner
  schema includes a mandatory `missing` field — text-only, no perception: the VLM reads
  the context against the vocabulary and names what it cannot express. Catches gaps that
  are *anticipatable from the context* (e.g., pair-programming → turn-taking).
- **Confirm-time probe (planned, zero extra cost).** When a conjunction fires and the
  VLM verifies the frame, it is additionally asked whether the claimed relation is what
  is actually noteworthy in the image — catching *misattribution* gaps (geometry fired,
  but the real story is outside the vocabulary).
- **Audit sampling (optional, deferred — the plan-time probe is structurally sufficient for vocabulary revision).** Vocabulary blind spots never
  fire, so they never reach the VLM — a structural blind spot. Remedy: sparse audits —
  occasional random frames, or frames flagged by the T/F log as suspicious (people
  present but all rows F for a long stretch), sent to the VLM with "is anything
  report-worthy happening that the watch-spec missed?" Sampled, not always-on, so cheap.

A low missing-rate across probes is empirical coverage evidence; named gaps are concrete,
citable inputs for vocabulary revision. The vocabulary is versioned and editable by
design — the contribution is the mechanism (VLM composing watch-specs over a
theory-grounded vocabulary), not this particular ten.

## Composition grammar — an open question, decided by the study

Two grammars are implemented in planner.py and compared as arms of the preliminary study:

- **restricted** — `watch` = up to 3 entries, each an AND over 1–3 ids with a time
  window; entries are alternatives (OR). Simple, easy to validate, easy to execute.
- **free** — entries may combine `all` (AND), `any` (OR), `not` (suppression), `then`
  (ordered sequence). More expressive — sequences in particular are socially meaningful
  (an F-formation *forming* is `10 then 6`, not `10 and 6`) — but a larger error surface.

Decision rule: if the free arm rarely uses `any/not/then`, or uses them without
face-valid need, ship restricted and cite the runs; if `then` appears often and sensibly,
the executor gains sequence support.

## Conjunction semantics (the watch-spec the VLM emits)

```json
{
  "watch": [
    {"all": [3, 5], "within_s": 2.0, "label": "someone seeks the robot up close"},
    {"all": [2, 4], "within_s": 2.0, "label": "showing something to each other"}
  ],
  "single_ok": [9],
  "duration_s": 600,
  "why": "context says they are assembling hardware together; handling and showing matter"
}
```

- `all` + `within_s`: every member relation must have been T within the window, each with
  persist ≥2 frames (strict same-frame conjunction fails at ~2 fps).
- When a conjunction is satisfied → record (frame + a slice of the T/F vector ±N s around
  the moment + label). **The same conjunction over the same participants enters a 60 s
  cooldown** (RelationGate reused with conjunctions as keys).
- CV logs the full 1–10 truth vector every frame → `relation_log.jsonl` (analysis data in
  itself: it shows how a conjunction *forms*, e.g. an F-formation assembling).

## Example conjunctions (few-shot for the planner prompt)

- **5(→personal) + 3** — someone approaches the robot and looks at it → seeking interaction
- **7(approach) + 1(gazing at the same object)** — walking toward what you look at → intentional act (Michalowski's engagement escalation)
- **2 + 4** — joint attention + pointing → "look at this" (the full joint-attention package of developmental psychology)
- **10(1→2) + 6** — a second person arrives and a face-to-face formation settles → a conversation begins (Kendon's F-formation forming)
- **9 + 8** — hands-on + leaning-in → focused manipulation; also usable as a NEGATIVE rule (do not record / do not interrupt)

## Mapping onto existing code (a re-arrangement, not a rewrite)

| New component | Source |
|---|---|
| T/F evaluators (rows 1–4) | gaze.py as-is; rows 5–10 each ~20–40 lines of new geometry |
| watch-spec executor | perception/watch_exec.py -- WatchExecutor, keyed to conjunctions |
| VLM planner | Gemini structured-output call over independent spatial images; offline mode as usual |
| recording / feed / web UI | publish / serve_ui / render reused unchanged |
| optional confirm step | judge's `confirm` kept: when a conjunction fires, the VLM may double-check the image (precision) |

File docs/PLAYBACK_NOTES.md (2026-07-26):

# Feetech SC playback notes (Arduino)

## Setup

- Library: `SCServo` (Feetech's official Arduino lib, a.k.a. FTServo). Bus servos share one serial line — give pan ID=1, tilt ID=2 (use Feetech's FD software or the lib's ID-write example once).
- Wiring: servo TTL bus ↔ board UART (needs the Feetech TTL interface board or a half-duplex circuit). Power servos from a separate 5–7.4V supply, common ground.

## Calibration

1. Mount horns with the head facing "forward" while both servos are at position 512 (center = rig zero).
2. If mechanical zero is off, store per-servo offsets in firmware: `unit = csv_unit + offset`.
3. Verify travel: command 512±100 slowly, confirm direction matches Blender (+pan = same turn direction). If reversed, mirror in firmware: `unit = 1023 - unit`.

## Playing a clip

CSV rows are (t_ms, pan_unit, tilt_unit) at ~33 ms spacing (30 fps). Two options:

**Option A (simple, recommended first):** timed stepping — every 33 ms send `WritePosEx(id, unit, speed=0, acc=0)` with the next row. Bus servos glide between close targets; at 30 Hz this looks smooth.

**Option B (smoother):** use the servo's own time-based move — send target + travel time (`RegWritePosEx` with time = gap to next waypoint, then `RegWriteAction()` to fire pan+tilt simultaneously). Prevents pan/tilt de-sync.

Convert CSV → C array with a one-liner (run on laptop):
```bash
python3 -c "
import csv,sys
rows=list(csv.DictReader(open(sys.argv[1])))
print('const uint16_t CLIP[][3] PROGMEM = {')
print(',\n'.join(f'  {{{r[\"t_ms\"]},{r[\"pan_unit\"]},{r[\"tilt_unit\"]}}}' for r in rows))
print('};')" export/S3_ack.csv > S3_ack.h
```

## State machine integration

Each state plays its clip: looping (S1, S5, S8) or one-shot (S2, S3, S4, S6, S7). On state transition, interrupt the current clip and ease to the new clip's first pose over ~200 ms (send it as a single timed move) — avoids visible snapping.

## Safety

- Firmware clamps: never command outside [pan: 512±512 → mechanical limit; tilt: your mechanical range in units].
- On boot: slow move to center over 1 s, then enter S1 idle.

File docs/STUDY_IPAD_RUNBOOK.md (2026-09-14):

# STUDY / FILMING RUNBOOK — the English tablet

Branch `study-ipad-en`. Cut from `demo-expo-2026`, so it keeps the tablet the
exhibition build introduced, and it takes the request back from the tablet and
gives it to the robot.

|  | `cassie/tomato` (study) | `demo-expo-2026` (stand) | **this branch** |
|---|---|---|---|
| the request | spoken, PTT | tapped, 3 Japanese cards | **spoken, PTT** |
| language | English | Japanese | **English** |
| participant's screen | a static review page, second process | the whole interface | **the whole interface** |
| head tap | Correct only | Correct **and** wake | **Correct only** |
| `REPLAN_PERIOD_S` | 540 | 0 | **0** (inherited — see §6) |

Use it for Study 2 sessions run with a tablet, and for the teaser shoot.

---

## 1. Before the participant — is the VLM fast today?

```bash
python3 -m robot.tools.net_check
```

Read **FLOOR** (RUNBOOK §2b). 1–2 s means planning lands in 5–8 s and the sweep
screen carries it. 7–10 s means ~20 s, which is survivable in a study and bad on
camera — if you are filming, come back later.

A slow FLOOR is Google queueing and **cannot be fixed from here**: not by the
network, not by the tier, not by sending fewer frames. RTT 0.03 s while FLOOR
swung 1.3 → 20 s, and a hotspot made RTT worse without touching FLOOR.

**Do not change `NOTICEBOT_GEMINI_MODEL`** — it is pinned for the study.

---

## 2. Start it — ONE terminal

```bash
cd ~/Documents/Claude/Projects/potatobot/notice-sidekick-runkit
git checkout study-ipad-en

python3 noticebot_loop.py \
    --cam 0 \
    --cores3 /dev/cu.usbmodem11201 \
    --detector yoloworld \
    --cv-hz 4 \
    --feedback robot \
    --serve --conf 0.2
```

Identical to the study command. It prints two addresses:

```
open  http://localhost:8000                 <- yours
      http://192.168.x.x:8000/booth         <- type THIS on the iPad
```

There is no second terminal. RUNBOOK §4b's file server serves a static page that
must outlive a loop restart; this tablet has to *follow* the loop, so it lives in
the same server.

**One run per session.** A restart opens a new session folder, and the tablet's
story list is one `attention_log.jsonl`.

---

## 3. The iPad, once

Open the printed address in Safari, then:

1. **Share → Add to Home Screen.** Opening from there is full-screen with no
   address bar, so a participant cannot navigate away mid-session.
2. **Settings → Accessibility → Guided Access** on. Triple-click to lock it.
3. **Settings → Display & Brightness → Auto-Lock → Never.**

### Both devices on the same network, and not the building's

University and venue Wi-Fi very often has **client isolation**: two devices on
one SSID cannot reach each other, and there is no fixing it on the day. Use a
travel router or a phone hotspot with the laptop reaching the internet through
the same box.

The test: if `localhost:8000/booth` works on the laptop and the iPad hangs, it
is isolation.

---

## 4. What a session looks like

```
   asleep         (-_-) z z z on both screens, and one line on the tablet:
                  hold the button on the robot and tell it what to watch for.
                  NOTHING on the tablet is tappable here -- the way in is
                  the robot.
1  hold PTT       It lifts its head.                                    (S2)
                  The tablet shows three breathing dots.
2  speak          Their own words. When Whisper returns, the sentence
                  appears LARGE on the tablet.
                  Misheard -> the text goes red-brown and says so. They
                  hold the button and say it again. This is the whole
                  reason the sentence is on screen: a misread caught here
                  costs five seconds, and a misread caught at the sweep
                  costs the turn.
3  nod            Acknowledge. 1.7 s, no page of its own.               (S3)
4  sweep          Five stations appear as they are captured; when the plan
                  lands the boxes are drawn and the chosen one goes red.  (S4)
5  watch          SAME SCREEN. The red cell is now the LIVE camera; the
                  other four stay as sweep stills.                      (S5)
   touch head     -> Correct. It looks elsewhere and the red frame moves
                  with it. THE TAP DOES NOT WAKE IT on this branch.     (S6)
6  call           Chirp + lean. The same prompt on the tablet and on the
                  robot's screen.                                       (S7)
7  OK             Either screen. The robot nods and goes straight back to
                  watching; the TABLET stays behind and waits for the
                  report -- 6-45 s, with a face and a moving bar.
8  the story      The strip at full height, swiped sideways, sentence
                  underneath. `close` goes back to following the robot.
```

### The two extra touches on the room screen

- **Tap the red cell** → the live view fills the screen, everything else dims,
  the rule stays lit. Tap again to go back.
- **The sixth cell is the rule** — relation chips that light as each becomes
  true, the AND/OR/THEN between them, and the object they are bound to.

---

## 4b. Keys, from the terminal the loop was launched in

| key | does |
|---|---|
| `1`…`8`, `0` | force a state (1 Idle · 2 Attend · 3 Acknowledge · 4 Scan · 5 Watch · 0 Settle · 6 Correct · 7 Call · 8 Error) |
| `g` | S2_LISTEN — lifts the head without the button, for testing |
| `f` | force a finding — the keyboard twin of **notice this NOW** |
| `r` | torque off (press a state key to re-engage) |
| `q` | quit |

They work whether or not the preview window has focus.

---

## 5. Checking the tablet without the robot

```bash
python3 tools/booth_preview.py -o ~/Desktop/bp
open ~/Desktop/bp/index.html
```

Eleven frozen screens, no camera, no serial, no cloud. **Resize the window to an
iPad's shape before judging any size** — everything is `clamp()`ed off the
viewport, so a tall desktop window will lie to you about exactly the thing you
opened it to check. The sweep photographs deliberately do not load.

---

## 6. When it does not fire

Both controls are on the **laptop's** page (`http://localhost:8000`, LIVE tab,
**IF IT MISSES THE SCENE**):

- **notice this NOW** — skips the trigger and the confirmation judge. The robot
  performs the notice and collects the story exactly as if it had fired.
- **look around again** — a fresh sweep on the same request.

Give it ten seconds first. For a **study session** prefer waiting: a forced
notice is not the system behaving. For a **teaser take** a forced one is
legitimate insurance, but shoot the real trigger for the shot you actually use —
the record names which it was.

`REPLAN_PERIOD_S` is **0** on this branch, inherited from the stand, where a
self-directed sweep landing mid-visit read as a fault. **If you are running
Study 2 sessions on this branch, set it back to 540** or the design's one
self-directed sweep never happens and the session is not an instance of the
system being studied.

---

## 7. End of a session

Ctrl-C once. The teardown flushes any story still collecting, so the last finding
is on disk rather than lost with the process.

`session_feed/<run>/` is the whole session: every report, every sweep, every LLM
call, and `review.html`.

---

## Troubleshooting

| symptom | first suspect |
|---|---|
| iPad hangs, laptop is fine | client isolation (§3) |
| tablet stuck on the sleep screen | the loop is not publishing — check the terminal for a traceback |
| the sentence never appears on the tablet | `stt.probe()` at startup — a dead input gives a wav of zeros, which is indistinguishable from saying nothing |
| Whisper keeps mishearing one word | it is on screen now; have them rephrase rather than repeat. The acceptance test only asks "is this a request at all" |
| tapping the head does nothing | `touch_test.py` first; then whether it is in a state that accepts it. **It no longer wakes the robot** |
| nod, then sleep, no sweep | an `arm_next` ordering regression — every caller must `request()` first and `arm_next()` second |
| the story list is empty | the loop was restarted; the list is one `attention_log.jsonl` |
| planning takes 20 s | `net_check`. If FLOOR is high it is Google, and nothing here helps |
| the live cell flickers black | the stream got moved inside the markup `render()` rewrites — it must stay outside `#app` |
| a size on the tablet ignores the number in the source | a `font:` shorthand with `inherit` in the family slot. Invalid, so the whole declaration is dropped. `tests/test_booth_listen.py` guards it |

---

## What was NOT touched

The VLM path is byte-identical to `s2-study-build`: `perception/`,
`planning/planner.py`, `planning/judge.py`, `planning/provider.py`,
`planning/gemini_provider.py`, `robot/`, `motion/`. The clip set in
`motion/clips/*.csv` is unchanged and remains the motion authority
(`STUDY_CLIP_AUTHORITY.md`).

Changes are confined to `webui/booth.py`, `webui/server.py` (two routes and two
state fields) and three places in `noticebot_loop.py`.

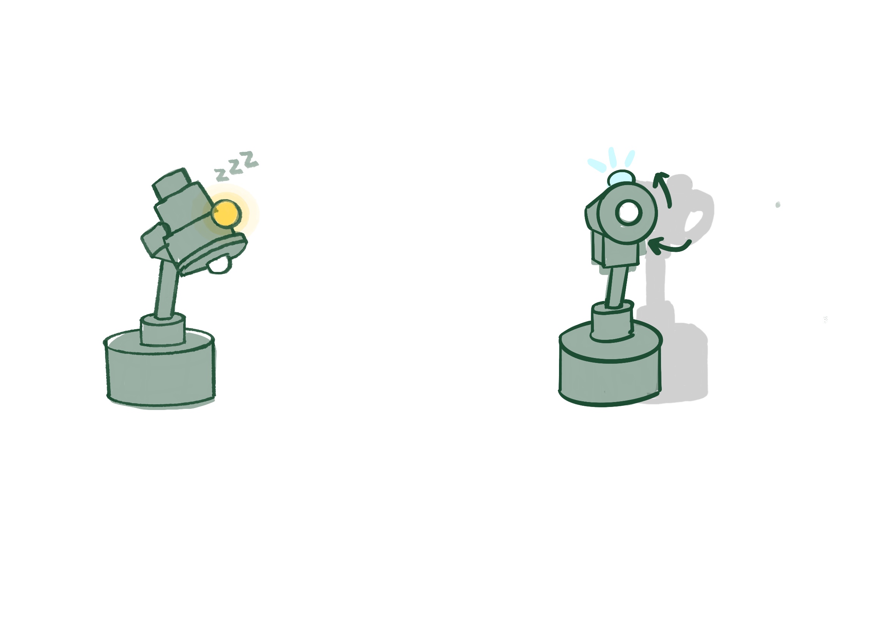
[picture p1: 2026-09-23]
motion/robot_art/Untitled_Artwork 5.jpg

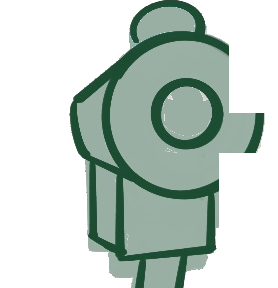
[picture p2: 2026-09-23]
motion/robot_art/head.png

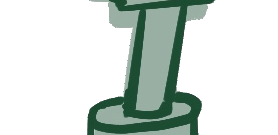
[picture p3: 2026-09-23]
motion/robot_art/neck.png

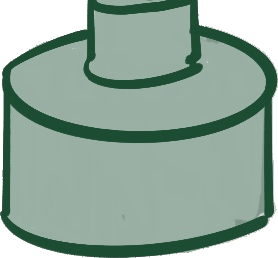
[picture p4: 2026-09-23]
motion/robot_art/base.png

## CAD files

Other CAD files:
motion/src/S1_IDLE.blend
motion/src/S2_LISTEN.blend
motion/src/S3_ACK.blend
motion/src/S4_PLAN.blend
motion/src/S5_TRACK.blend
motion/src/S6_FINETUNE.blend
motion/src/S7a.blend
motion/src/S7b.blend
motion/src/S8_ERROR.blend
motion/src/rig.blend

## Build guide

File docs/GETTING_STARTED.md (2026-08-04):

# Getting started on a fresh machine

Three tiers. Each one runs on its own and adds hardware to the one before it, so
when something breaks you already know which layer it is in.

| tier | needs | what you can do |
|---|---|---|
| **0 — logic only** | just Python | run the state-machine tests, inspect clips |
| **1 — motion only** | servos + FE-URT2 (+ CoreS3) | play any state, or walk the whole cycle. **This is the tier for studying the movement.** No camera, no VLM, no API key. |
| **2 — full loop** | + head camera + API key | a real session: speak, plan, watch, notice |

---

## 0. Logic only (5 minutes, no hardware)

```bash
git clone <this repo> && cd notice-sidekick-runkit
python3 -m venv .venv && source .venv/bin/activate     # or conda; Python 3.10+
pip install -r requirements.txt

python3 tests/test_session_flow.py
```

Expect `all paths pass` (86 assertions). This exercises every transition —
STOP mid-scan, a transcript that arrives after its timeout, a tap in the wrong
state — with a fake clock and no devices. If this fails, do not plug anything in;
something is wrong with the checkout, not with your robot.

You can also inspect the motion library without hardware:

```bash
python3 robot/tools/check_clips.py motion/clips
```

It validates every CSV against this build's calibrated limits and reports peak
velocity. `GO` means the clips are safe to play.

---

## 1. Motion only — the tier for studying movement

**This is what you use when the question is about the movement itself.** It
touches the servo bus and nothing else: no camera is opened, no model is loaded,
no network call is made.

### Wire it up

Full detail in `HARDWARE_SETUP.md`. The three things that most often go wrong:

1. **The servo bus needs its own 5–6 V supply** on the FE-URT2's blue screw
   terminal. The board back-feeds USB 5 V through a diode, so a servo will answer
   at **4.3 V with no external supply at all**  enough to read registers. **If the bus reads 4.3 V, your external power is not arriving (Now a battery box with 4 batteries is used for current version).**
2. **The signal-level slider goes to 5 V**, not 3.3 V.
3. **Servo IDs must be 1 = pan, 2 = tilt, 3 = nod.** New servos all ship as ID 1,
   and three servos answering as ID 1 gives you total silence on the bus — which
   looks exactly like nothing being plugged in.

### Find the bus

```bash
python3 robot/tools/check_bus.py                 # probes ports and baud rates
export NOTICEBOT_PORT=/dev/cu.usbmodemXXXXXXX    # put this in ~/.zshrc
```

macOS calls the adapter `/dev/cu.usbmodem<location-id>`, and the name changes if
you replug into a different port or hub. `check_bus.py` probes rather than
guessing, so re-run it rather than trusting an old value.

Expect three lines with **~6 V**, not 4.3 V.

### (NOT NECESSARY with the SAME hardware) Calibration — read before you play anything 

`robot/calibration.py` holds numbers that describe **the physical build they were
measured on**. If you are running someone else's servos, or the neck has been
rebuilt, they are wrong for you and the robot will drive into its end stops.

```bash
python3 robot/tools/jog.py            # drive one joint by hand; c = centre, [ ] = limits
```

It writes `calibration.py` for you. This is measurement, do not
nudge the values until it looks right.

### Play the motion

```bash
# ONE state, then hold. This is the one you use to study a single movement.
python3 robot/clip_player.py S7a
python3 robot/clip_player.py S4_PLAN

# THE WHOLE CYCLE, in designed order: S1 → S2 → S3 → S4 → S5 → S6 → S7a → S7b
python3 robot/clip_player.py

# every state including S8_ERROR, which sits outside the cycle on purpose --
# it is not a step in the communication, it is what happens when the
# communication cannot continue
python3 robot/clip_player.py --all

# with the CoreS3 attached, so the LED envelope and the sounds play too.
# The LED level is authored INSIDE the clip, so it belongs to this tier.
python3 robot/clip_player.py --all --cores3
```

Two more, for when the movement looks wrong and you want to know why:

```bash
python3 robot/tools/play_on_hardware.py motion/clips/S4_PLAN.csv --dry-run  # read the CSV, touch nothing
python3 robot/tools/play_on_hardware.py motion/clips/S1_IDLE.csv --loop     # one clip on repeat
python3 robot/clip_player.py --cores3 --led-test    # LED only: is the firmware flashed?
```

**To change a movement you do not edit code.** Edit the `.blend` in
`motion/src/`, re-export, and drop the CSV into `motion/clips/`. See
`MOTION_AUTHORING.md`.

### Flash the CoreS3

Arduino IDE → open `robot/firmware/cores3_sidekick/cores3_sidekick.ino` →
board **M5Core S3** → upload. On boot it prints `IN HELLO cores3_sidekick v2`
and draws the idle screen with a big green PTT and a red STOP. 

---

## 2. The full loop

Everything in tier 1, plus:

```bash
export GEMINI_API_KEY=...            # the planner and five-frame event confirmer
python3 noticebot_loop.py --list-cams
```

`--list-cams` prints a verdict per camera. The head camera is the InnoMaker
OV4688: asked for 2560×1440 it complies and returns a wide 16:9 frame. A Mac's
built-in camera answers with something square (1552×1552) because of the Center
Stage sensor — **square is the giveaway, not size.**

### First run: go offline

```bash
python3 noticebot_loop.py --cam 0 --cores3 --serve --offline --no-stt --feedback console
```

`--offline` disables all Gemini calls and uses deterministic Planner/Judge output.
Confirm the motion, plan installation and screens work
before you add the network to the list of things that might be wrong.

Then open <http://localhost:8000> and watch for these three lines in the
terminal. A missing one tells you which layer did not come up:

```
[cv]  ready (gdino)
[cores3] /dev/cu.usbmodemXXXX answered PING
```

The first `whisper ready` on a new machine takes a while — it downloads the
model. The loop warms it at startup precisely so that no participant is ever the
one waiting for it.

### The real thing

```bash
python3 noticebot_loop.py --cam 0 --cores3 --serve --no-stt --feedback console
```

Walk one round to confirm the whole chain:

1. Hold **PTT** on the CoreS3 — the bar moves while you speak.
2. Release — screen says `waiting...`.
3. Whisper answers — the robot nods, screen says `I heard you.`, and your
   sentence appears on the web page under the live view.
4. The head sweeps (`planning...`), then holds. **It stays on `planning...`
   while the VLM is still deciding** — that is correct, not a hang.
5. The plan lands: THE PLAN panel fills with watch entries, the head turns to the
   richest angle, screen changes to `tracking...`.
6. Stage the requested event. CV opens a candidate, Gemini confirms five temporal
   frames, and the terminal prints exactly one `[FEEDBACK] ...` line. No S7 motion
   happens in the default console mode.
7. Press **OK** on the board, or leave it 30 s.
8. Press **STOP** at any point — the robot returns to idle *and* the watch-spec
   is torn down.

After calibration and the console E2E are both proven, `--feedback robot` allows
confirmed events to enter S7. The `f` key remains a manual motion override.

### Useful flags

| flag | for |
|---|---|
| `--offline` | no VLM narration; captions are the grounded trace |
| `--no-cv` | no detector or pose. THE PLAN stays empty; `f` is the only finding |
| `--no-cam` | servos + CoreS3 only |
| `--no-stt` | no Whisper; type requests into the web UI instead |
| `--detector gdino` | default open vocabulary detector — the VLM's tiers re-prompt it live |
| `--detector yoloworld --cv-hz 4` | tested lower-latency open-vocabulary path (requires Ultralytics) |
| `--feed-dir <path>` | where findings and sweeps are written |

### Where a session ends up

`session_feed/` (gitignored — it is data saved on local machine):

```
frame_<id>.jpg               the comic strip of one noticed moment
thumb_<id>.jpg               its card in the feed
attention_log.jsonl          one line per record: note, story, truth vector, worth
sweeps/<timestamp>/
    panorama.jpg             local researcher visualization; Gemini read independent views
    pan_+030.jpg …           each angle, with the VLM's boxes drawn by tier
    plan.json                seen / detect / focus, the watch-spec, and coverage
```

`plan.json`'s `coverage` is worth reading after a session: it counts, per planned
object, how many angles the VLM boxed it in. A zero means it planned around
something it never actually saw.

---

## Debug

| symptom | look here |
|---|---|
| bus reads 4.3 V | external power is not reaching the screw terminal |
| total silence on the bus | two servos sharing an ID — `check_bus.py --scan-ids` |
| port disappeared after replugging | re-run `check_bus.py`; usbmodem names move |
| robot drives into its end stop | `calibration.py` is not this build's — re-measure with `jog.py` |
| screen shows something other than the nine screens | old firmware; reflash |
| first PTT fails, second works | you pressed before `[stt] whisper ready` |
| THE PLAN panel is empty | no `GEMINI_API_KEY`, or you passed `--no-cv` |
| NOTICED stays 0 after a finding | wait out the 6 s linger; the tab shows `+1` while collecting |

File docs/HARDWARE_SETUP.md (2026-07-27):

# Hardware setup

Everything you need to bring the neck up on a fresh machine: wiring, power,
servo IDs, calibration, and flashing the CoreS3. Written from the first
bring-up session, with the wrong turns kept in -- most of them are not obvious
and every one cost hours.

**Last verified 2026-07-27.** All three joints calibrated, all eight clips play,
the full state machine runs.

---

## The robot

**3 DOF: pan (turn) → tilt (neck lean) → nod (head).** Animation-first motion
design (Hoffman & Ju) in **Blender 5.2**. All files in `motion/` and `robot/`.

- `motion/blender/` — `build_pantilt_rig.py`, `repair_rig.py`, `add_nod_joint.py`,
  `build_shell.py`, `setup_scene.py`, `export_clip.py`, and clip generators
  `generate_s3_ack.py` / `generate_s4_sweep.py` / `generate_s6_finetune.py` /
  `generate_s7_found.py` / `generate_s7_beckon.py`.
- Motion library v0.1 = 8 states (S1 idle, S2 listen, S3 ack, S4 plan/sweep,
  S5 track, S6 fine-tune, S7 found+beckon, S8 error).
  Rendered demo: the demo render (not committed -- ask cassie).
- Motion grammar: horizontal shake = negation (S6 only); vertical = affirm /
  beckon; loop clips (S1/S5/S8) are pure loops.

### Exported clips
`export_clip.py` writes `motion/clips/<CLIP>.csv` with columns
`t_ms, pan_deg, tilt_deg, nod_deg, pan_unit, tilt_unit, nod_unit`
where `*_unit` is the Feetech 0–1023 position (300° travel, rig zero = 512).

CSVs are build artefacts. **Never hand-edit them** -- see `docs/MOTION_AUTHORING.md` for why, and for the export workflow.

---

## Hardware as built

- **3× Feetech SCS0009** serial bus servos. **IDs: pan=1, tilt=2, nod=3.**
  They report `model=1284`.
- **FEETECH FE-URT2-C001** USB→TTL adapter. **CH343 chip → enumerates as
  `/dev/cu.usbmodem*`, not `usbserial*`.** Measured port on this Mac:
  `/dev/cu.usbmodem5B790340551` @ **1 000 000 baud**.
- SCS0009 has only ONE cable (no pass-through), so the three servos are **not**
  daisy-chained: nod goes to one GVS socket, pan+tilt share the other through a
  small splitter PCB.
- **Camera: OV4688 UVC module**, 32×32 mm, 4×M2 holes.
  **FOV D=71°, H=58°.** Up to 4 MP (2688×1520) @30 fps, 2K @60, 1080p @60;
  YUY2 + MJPEG; UVC class, driver-free. HDR/WDR, OmniBSI-2 BSI.
  *(Supersedes the old Waveshare OV2735 / 96° figure — that is no longer true
  and the 38° of lost field changes the S4 sweep maths.)*
- Print/assembly spec + STLs: `robot/cad/`.

### Power — read this before plugging anything in
- **The servo bus needs its own 5–6 V supply on the blue screw terminal.**
  SCS0009 is a 6 V-class servo. The board accepts 4.8–12 V but V1 is a
  **pass-through to the servo V pin**, so 9 V or 12 V destroys the servos.
- The board **does** back-feed USB 5 V onto the bus through a diode, so a servo
  will answer at **4.3 V with no external supply at all**. That is enough to
  read registers and nothing more — it is not "working", and it masks a
  disconnected supply. If the bus reads 4.3 V, external power is not arriving.
- Board LED is on the USB/logic rail. **It does not light from the screw
  terminal alone.** That is normal, not a fault.
- The serial signal level slider should be at **5 V**, not 3.3 V.
- Type-C and the UART header are alternative *command* sources — pick one. That
  is unrelated to power; USB and external power are used together.

---

## Software

```bash
python3 -m pip install feetech-servo-sdk pyserial
export NOTICEBOT_PORT=/dev/cu.usbmodem5B790340551   # put this in ~/.zshrc
export NOTICEBOT_BAUD=1000000
```

> **The pip package is `feetech-servo-sdk`; the import name is `scservo_sdk`.**
> `scservo-sdk` does not exist on PyPI. The pip package ships only the
> low-level `PacketHandler` — there is **no `scscl` class** like in Feetech's
> C++ SDK or GitHub folder. `robot/scs.py` supplies the SCSCL register map
> and packet packing on top of it.
>
> SCS/SCSCL is big-endian: `PacketHandler(1)`. Using 0 (the STS/SMS setting)
> does not error, it just returns byte-swapped garbage positions.

`robot/` and `robot/tools/`, in the order you use them:

| script | what it does |
|---|---|
| `robot/scs.py` | SCSCL layer: ping, read pos/load/voltage/temp, write pos, torque, set ID |
| `robot/tools/check_bus.py` | find port + baud, ping IDs, `--watch` live voltage, `--noise` sensor steadiness, `--set-id` |
| `robot/tools/jog.py` | interactive per-joint jogging; records centre `c` and limits `[` `]`; writes `calibration.py` |
| `robot/calibration.py` | per-joint CENTRE / LIMITS / OFFSET / INVERT. Config, hand-editable |
| `robot/tools/play_on_hardware.py` | plays a clip CSV on the clip's own clock. `--dry-run`, `--center`, `--loop`, `--relax` |

Note zsh: `P="--port X --baud Y"; script.py $P` does **not** work — zsh does not
word-split unquoted expansions. Hence the environment variables.

---

## Calibration (measured 2026-07-26)

| joint | id | centre | limits | usable angle | offset | invert |
|---|---|---|---|---|---|---|
| pan | 1 | 508 | 268–768 | −70° / +76° | −4 | **True** |
| tilt | 2 | 218 | 118–348 | −29° / +29° | −294 | **True** |
| nod | 3 | 560 | 470–720 | −26° / +47° | +48 | False |

- **pan's limit is the cable loom through the axis, not the servo.** The USB
  camera cable is the stiffest thing in it.
- **tilt has no mechanical stop** — it runs to the servo's electrical end (unit
  58 was reachable by hand). Its limits are chosen from what the clips need
  plus margin, not from where it stops.
- pan and tilt run mirrored vs the Blender render, confirmed against
  the demo render (not committed -- ask cassie) using S2_LISTEN (pan) and S3_ACK (tilt).
- nod: two frames that run opposite, and mixing them up is easy —
  **in Blender positive nod = head UP**; **on the bus a higher unit = head
  DOWN**. `INVERT["nod"]=True` reconciles them. Always author against the
  render; the servo frame is what INVERT absorbs. (nod's True is provisional —
  set from the viewport, not yet seen move on hardware.)
- The pan horn originally sat so the working arc **straddled the pot's 0/1023
  seam**, which makes position control undefined. It was remounted. If pan
  readings ever wrap 1023→0 again, remount rather than trying to fix it in
  software.

`LIMITS` are a guard rail, not a record of travel: wider than the motion needs,
well short of anything that can jam. `play_on_hardware.py` refuses to play while
any joint is listed in `UNCALIBRATED`.

---

## Coverage design for S4 (the scan)

The study only needs the **forward ~180°**; behind the robot does not matter.

**±60° pan sweep + 58° H FOV = −89°…+89° = 178° covered.** The cable-imposed pan
limit and the coverage requirement happen to land on the same number, so there
is nothing to gain from re-routing the loom for coverage.

Station spacing must stay **under 58°** or the sweep leaves unphotographed gaps
(invisible in the render; shows up later as the VLM "missing" objects).
`generate_s4_sweep.py` raises rather than generating a gapped sweep.

| N | step | overlap | length |
|---|---|---|---|
| 3 | 60° | **gap** | 5.0 s |
| 4 | 40° | 31% | 5.6 s |
| **5** | **30°** | **48%** | **6.2 s** |
| 7 | 20° | 66% | 7.4 s |

N=5 is the working choice: ~6 s reads as deliberate scanning without making the
participant wait, and 30° steps resolve the "richest position" finely enough.

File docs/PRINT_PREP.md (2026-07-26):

# 3D-Print Prep Spec — 3-DOF Sidekick (pan / tilt / nod, 3× Feetech SCS0009)

The Blender shell is a **massing model** (form only). Printable parts are built in Rhino/Fusion from this spec: real servo pockets, horn interfaces, bearings, screw bosses, tolerances, and split lines. Verify every servo/camera dimension against its datasheet before printing.

## Component dimensions (verify!)
- **SCS0009** bus servo: body ≈ 23.0 × 12.0 × 22.0 mm; two mounting tabs (span ≈ 32 mm, ~2.5 mm thick, 2 holes ~ Ø2); output spline on top face, offset from center; comes with horns + center screw. Stall ~1.3 kg·cm @6V. 3-wire TTL bus (daisy-chain: pan ID1, tilt ID2, nod ID3).
- **Camera** Waveshare OV2735: PCB 25 × 25 mm (mount holes 21 mm pitch, Ø2), lens barrel Ø14 mm, protrudes ~16 mm, total depth 22 mm, FOV 96°, USB-C or 4-pin.

## Servo mounting — the universal rule
Each joint = **(a) body captured in a pocket + (b) horn drives the rotating part + (c) a passive pivot on the opposite side of the axis.** Never let the servo spline be the only support for a load.

Print each servo pocket to **body +0.3 mm** clearance; secure with the 2 mounting-tab screws into **M2 heat-set inserts** (don't screw straight into PLA). Use the Feetech-supplied horn as an embedded interface: screw your printed rotating part to the horn, then the horn clips onto the spline.

### Pan (in the base)
- Body vertical, spline up, captured in a pocket in the **fixed lower base**.
- Horn screws to the underside of the **rotating hub**.
- **Load support (critical, SCS0009 is weak):** add a large-diameter **turntable ring race** between fixed base and rotating hub — two printed rings with a groove for Ø4–5 mm airsoft BBs, or an off-the-shelf thin-section bearing / lazy-susan. The servo then supplies torque only.
- Split line: base = `base_lower` (servo + electronics + BB race lower half) + `hub` (rotating, race upper half).

### Tilt (in the joint hub)
- Body horizontal in the hub, spline on +X side.
- Horn drives the **outer telescoping tube** (fixed to the tilt output).
- Opposite (−X) side: **passive pivot** — a Ø3 pin into a printed boss with a small bearing or PTFE washer, coaxial with the spline.
- Hub is a 2-part clamshell (split on the XY plane) so the servo drops in.

### Nod (top of the inner tube)
- Body horizontal at the top of the **inner tube**, spline on +X.
- Horn drives the **head assembly** (head + camera live here permanently).
- Opposite side: passive pin/bearing.
- Nod servo + head form one non-removable unit (so neck length changes never disturb wiring at the head).

## Shell split into printable parts
1. `base_lower` — pan servo pocket, MCU bay, cable exit at rear, BB-race lower.
2. `hub` — BB-race upper + tilt servo clamshell (2 halves) + tilt passive-pivot boss.
3. `neck_outer` — outer telescoping tube, fixed to tilt horn (bayonet or 2 screws).
4. `neck_inner` — inner tube, carries nod servo + head; detent spring tab.
5. `head_front` + `head_back` — cone head split along its axis (lens hole in front; camera board captured between halves via 21 mm-pitch bosses); LED window on top-front.
Joints between parts: M2 screws into heat-set inserts, or snap-fit + screw for the head.

## Telescoping neck (3 positions: 40 / 80 / 120 mm)
Two concentric tubes, **diametral clearance 0.3–0.4 mm** (PLA-PLA binds/wears — prefer PETG for the sliding pair, or line the contact with PTFE tape).
- **Primary lock — spring detent:** a thin cantilever tab on the inner tube with a bump; three windows in the outer tube at 40/80/120 mm. Push tab to release, slide, click. Print the tab wall ~0.8–1.0 mm so it flexes without snapping.
- **Fallback — pin lock:** one hole in inner tube, three in outer; a captive Ø3 detent pin.
- Print tubes **vertically** for concentric roundness. Chamfer the inner tube's leading edge so it doesn't catch.
- **Wiring:** the nod servo's 3-wire bus runs down the inner tube; coil ~120 mm slack in the hub so the longest extension never tugs. All three servos share one bus down through the neck to the base.

## Tolerance & print checklist
- Servo pockets: body +0.3 mm; horn screw holes: tap size for M2 self-tap or insert.
- Sliding tubes: +0.35 mm diametral; test-print a 20 mm coupon pair first.
- Heat-set inserts (M2 brass) at every screw joint; don't thread PLA directly.
- Layer orientation: print the neck tubes and the stalk upright; print the head halves face-down on the split plane; the thin neck's weak axis is the layer line — keep bending loads off it or print in PETG/nylon.
- Weigh the finished head assembly; confirm < ~60 g so the nod & tilt SCS0009 hold it at the 12 cm extension (see neck_feasibility.py).

## Order of operations
1. Rhino: model each printable part from this spec around imported servo + camera dummies (draw them at true dims).
2. Print coupons: one servo pocket + one tube pair — verify fit before committing.
3. Print parts, install heat-set inserts, mount servos, set IDs (1/2/3), route the bus.
4. Assemble, hang-test the neck at 12 cm, then run the exported motion CSVs.

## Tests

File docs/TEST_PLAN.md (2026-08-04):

# Integration test plan — motion library → full session

Staged bring-up for the NoticeBot session rig. **Each stage adds exactly one
device or one layer**, so a failure is attributable to what was just added. Do
not skip ahead: the failure modes in this system are almost all silent, and a
combined run tells you nothing about which of four things is wrong.

Every stage has a numeric pass criterion. "Looks about right" is not decidable
in a system with three devices, a timing budget and a resolution floor — and it
is the reason several of the earlier problems here cost an afternoon each.

Written 2026-07-26. Target: HRI 2026 Design track, deadline 2026-09-18.

---

## Before every session

```bash
cd <repo root>          # all commands below are run from there
python3 robot/tools/preflight.py --cam 0
```

Must print **GO**. It checks: calibration complete, clips clean, state table
matches the clips on disk, three servos answering, bus voltage, torque enabled,
camera index yields a frame of the right size.

**No port to set.** Serial paths are probed, not configured: macOS names a
usbmodem device after its USB *location id* when the device has no serial number,
so the FE-URT2's path changes whenever it is replugged or comes up through a hub
— and the CoreS3 is also a usbmodem, so they cannot be told apart by name. The
servo bus is whichever port a servo answers a ping on; the CoreS3 is whichever
port greets with `cores3_sidekick`. `NOTICEBOT_PORT` is honoured if it still
exists, but it is only a hint. A hardcoded path is guaranteed to go stale, and it
fails as "the robot is dead" rather than "wrong port".

Camera indices move for the same reason — re-run `--list-cams` each session
rather than trusting a remembered number.

`NO-GO` on bus voltage below 5.0 V means external power is not reaching the bus
and the servos are limping on USB back-feed — nothing downstream is meaningful
until that is fixed.

---

## Stage 1a — motion alone

No camera, no CoreS3. Establishes that the timing contribution actually survives
on hardware.

```bash
python3 robot/tools/play_on_hardware.py --center
python3 robot/clip_player.py                       # walks the designed CYCLE
```

**Pass:**

| metric | threshold | why |
|---|---|---|
| dropped frames | **0** | a drop means the bus cannot sustain 30 fps; fix by lowering export fps in Blender, never in the player |
| max lag | **< 20 ms** | above this the ease curves are being re-timed, which is the thing the clips exist to preserve |
| `did not arrive` warnings | none | a joint that cannot reach its target is jammed, unpowered, or over-loaded |
| audible strain at any pose | none | check against `calibration.py` margins; S7b nod and S7a pan are the tight ones |

Then test the override: while `S5_TRACK` or `S8_ERROR` is looping, request
another state. It must take effect **within one frame (~33 ms)**, not at the end
of the loop. A player that finishes the clip first is unusable in a session.

`ST.CYCLE` deliberately excludes `S8_ERROR` — it is not part of the designed
cycle. Test it on its own: `python3 robot/clip_player.py S8_ERROR`.

---

## Stage 1b — the LED envelope

**The LED belongs to this stage, not to the CoreS3 stage.** Part of it is
authored *against the motion*: S4's shutter flash fires once the head has settled
at a station, S7b's peak lands on the top of the toss. Firmware cannot know when
those moments are, so the level travels in the clip's `led` column and the player
streams it. Verifying that needs the servos and the CoreS3 — but no camera.

Isolate the firmware first, because "no LED response" looks identical whether the
clips, the transport or the firmware is at fault, and the old firmware ignores an
unknown `EVT` silently:

```bash
python3 robot/clip_player.py --led-test --cores3      # touches no servos
```

**Pass:** the LED steps between dark and full five times. If it only keeps
breathing, `EVT LED` is not in the flashed firmware yet.

Then the real thing:

```bash
python3 robot/clip_player.py --cores3
```

**Pass:**

| metric | threshold |
|---|---|
| `N/9 clips carry an led envelope` | **9/9** (a *constant* column counts as none — see below) |
| `led updates sent` | hundreds, not 0 |
| lag / dropped | unchanged from Stage 1a |

Then watch the three places the sync actually matters:

- **S4** — five flashes, each *after* the head stops, not during the move
- **S7a** — a beat on each of turn / crane / head-up
- **S7b** — the peak on the *upward* stroke; dark on the way down

A constant `led` column is treated as "nobody authored an envelope for this clip"
and is not streamed. That is deliberate: the firmware only falls back to its own
breathing after 500 ms of silence, so streaming a constant would pin the LED solid
forever — and S1/S8 are exactly the states where looking alive matters most. Both
now have generators, so all nine should be authored.

---

## Stage 2 — camera alone

```bash
python3 ../../notice-sidekick-runkit/noticebot_loop.py --list-cams
```

**Pass:** the head camera appears at a known index at **1280×720 or better**. If
you see 640×480, that is probably the laptop's built-in — the index moves when
anything else USB is plugged or unplugged, so confirm it every session rather
than trusting a remembered number.

Sanity-check the stream on its own:

```bash
python3 noticebot_loop.py --list-cams
```

**Pass:** ≥ 15 fps sustained. The OV4688 does 1080p60 over UVC, so anything in
single digits means the format negotiated down — the loop requests MJPG for
exactly this reason.

---

## Stage 3 — camera + motion: the settled-frame gate

This is the stage that validates the head-mounted camera concept. Nothing else
tests it.

```bash
python3 noticebot_loop.py --cam 0
```

Press `4` for `S4_PLAN` and watch the overlay.

**Pass:**

- The badge reads **STILL** exactly **5 times** during the sweep — one per
  station — and **MOVING** in between.
- Frames captured while STILL are sharp; frames while MOVING are visibly
  blurred. If they are not, the sweep is too slow to be worth gating, or too
  fast for the exposure — either way that is a finding, not a nuisance.
- Each STILL window lasts **> 400 ms** (measured: 0.44–0.62 s).

Failure here is architectural, not a bug: it means either the camera needs a
shorter exposure, or `SETTLE_MS` in `noticebot_loop.py` needs to move, or the
station dwell in `generate_s4_sweep.py` needs lengthening.

### Use the existing web UI instead of the cv2 window

`webui/server.py` works unchanged — same `STATE`/`LOCK` contract:

```bash
python3 noticebot_loop.py --cam 0 --serve            # window + web
python3 noticebot_loop.py --cam 0 --serve --no-view   # web only
# open http://localhost:8000  (or http://<laptop>.local:8000 from a phone)
```

Until perception is wired there are no WatchExecutor entries, so the PLAN panel
shows the **state machine** in the same slots: the nine states with the current
one marked satisfied, and live lag / dropped / settled / pose underneath.

**Prefer `--serve --no-view` for anything with a participant in the room.** Not
for convenience: a laptop beside the robot showing bounding boxes and state names
tells the participant what to believe the robot is, which contaminates exactly
what the study is measuring. The web UI puts that screen somewhere else — a
second machine or a phone — and leaves the robot to speak for itself.

The browser's context box is also a free wizard channel: typing a sentence posts
to `/context`, which the loop reads and uses to enter the designed cycle at
`S2_LISTEN`. During a session, type what the participant actually asked.

---

## Stage 4 — CoreS3 input

The LED output was already covered in 1b; what is left is the *input* half —
touch and buttons — which nothing else exercises.

```bash
cd ../../notice-sidekick-runkit
python3 cores3_link.py /dev/cu.usbmodemXXXX
```

**Pass:** screen and chirps fire on the scripted `EVT` sequence; pressing the
buttons and tapping the body prints `IN TAP …` / `IN BODYTAP`.

---

## Stage 5 — all three

```bash
cd ~/Documents/Claude/Projects/potatobot
python3 notice-sidekick-runkit/noticebot_loop.py --cam 0 --cores3 --serve
```

Both `--cores3` and the servo port auto-detect; `--cam` still needs its index.

**Pass:**

- `c` enters the designed cycle and it runs `S2 → S3 → S4 → S5` unattended.
- Body tap during `S5` switches to `S6_FINETUNE` and returns to `S5`.
- Keys `1`–`8` still override instantly with all three devices live.
- LED colour follows `states.py` (`warm` in S1/S7, `cool` in S2–S6, `alarm` in
  S8) while the *level* still follows the clip.

**Watch for the one thing that only appears here:** serial contention. The servo
bus and the CoreS3 are separate ports, but both are driven from the same process,
and the CoreS3 redraws its screen inside its own `loop()`. Compare lag against
the Stage 1b figure — if it rose, the LED/screen traffic is stealing from the
player, and the fix is to throttle the CoreS3's screen redraw, not the motion.

---

## Stage 6 — perception: S4 station scoring (no VLM)

First autonomous layer. Detector only, no API key, so a failure is CV or wiring
and cannot be the model.

In `noticebot_loop.perceive()`: score each settled S4 frame with
`perceive.make_detector("gdino", vocab)` and keep the best index.

**Pass:** 5 scores per sweep, one per station, each attributable to the correct
pan unit. The sweep runs right-to-left (Blender +60° → −60°), and INVERT mirrors
that, so `ctx["stations"]` should come out in this order:

| station | Blender pan | servo unit |
|---|---|---|
| 1 | +60° | 303 |
| 2 | +30° | 405 |
| 3 | 0° | 507 |
| 4 | −30° | 610 |
| 5 | −60° | 712 |

If the order is reversed, the S4 CSV predates the direction change and needs
re-exporting.

---

## Stage 7 — retargetable S4

The richest station is chosen at runtime, but `RICHEST_DEG` is baked in at export
time. **S5 can simply be offset** (a static hold has no authored timing to
lose). **S4 cannot** — its return is a decelerating curve authored for one
distance, and stretching it rewrites the timing.

So: export **five S4 variants**, `RICHEST_DEG` set to each station, each with its
own correctly-derived `RETURN_F`. Then the player picks the variant.

**Pass:** all five variants pass `check_clips.py` with no clamping and no
handover problem into `S5_TRACK`.

---

## Stage 8 — S5 WatchExecutor

`watch_exec.py`'s `persist` counts **consecutive frames**, which assumes an
unchanging view. That assumption holds in `S5_TRACK` and nowhere else: S4's
viewpoint changes every station, so a streak accumulated across stations is
meaningless and can fire spuriously.

Run the relation gate **only while the state is `S5_TRACK`**, and reset its
streaks whenever the state changes.

**Pass:** a held relation fires once, then does not re-fire within `cooldown`;
breaking and re-forming it fires again.

---

## Stage 9 — judge / VLM

`judge.judge(jpeg, graph, taste)` on the S5 frame that fired, before `S7a`.
Needs `GEMINI_API_KEY`. Test `SECONDATTN_OFFLINE=1` first so the plumbing is proven
without the model in the loop.

**Pass:** a confirmed report reaches `S7a` within a latency you are willing to
have a participant sit through. Measure it — if it is seconds, the state machine
needs something to say while it waits, and that is a design question, not an
engineering one.

---

## Stage 10 — pilot, then study

1. **Dry run, no participant.** Full cycle end to end, three times. Nothing
   should require a keypress.
2. **Pilot with one colleague.** The thing to watch is not whether it works but
   whether the states are *read* the way they were designed — particularly
   `S6` as negation and `S7b` as a summons rather than a nod, since those two
   are the grammar claims.
3. **Session protocol.** Fix `SETTLE_MS`, cooldowns and the S4 station count
   before the first real participant; changing them mid-study makes the sessions
   non-comparable.

---

## Known constraints to design within

| constraint | value | source |
|---|---|---|
| pan travel | −70° … +76° | cable loom through the pan axis, not the servo |
| tilt travel | ±29° (guard rail; no mechanical stop exists) | chosen from clip demand + margin |
| nod travel | +26° up … −47° down (Blender signs) | measured; **up is the tight side**, and S4/S5/S7 all use it |
| servo resolution | 1 unit = 0.293° | SCS0009. Below ~8 units nothing visibly moves |
| slow + small + smooth | **not achievable** | step count is set by amplitude; stretching the duration only spreads the same steps |
| speed ceiling | 200°/s authored, 120°/s for unauthored moves | 200 is a no-load figure at 6 V; the rig is loaded and on batteries |
| camera | OV4688 UVC, H-FOV 58° | station spacing must stay under 58° or the sweep leaves gaps |
| forward coverage | 178° = 2×60° sweep + 58° FOV | matches the study requirement; widening the sweep buys nothing |

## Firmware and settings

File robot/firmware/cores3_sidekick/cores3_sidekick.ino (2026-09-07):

/*
 * cores3_sidekick.ino — NoticeBot participant I/O board  ·  M5Stack CoreS3
 * -----------------------------------------------------------------------
 * v2 (2026-07-26). The board owns three participant-facing channels and nothing
 * else: SCREEN, SOUND, and the LED antenna. Servos are on the FE-URT2, driven
 * from the laptop.
 *
 * WHAT WAS REMOVED, and why it mattered. v1 carried a second, older UI: a
 * three-button layout with an EAGER/CALM personality toggle, plus a dozen legacy
 * EVTs (ARMED / WATCH / PROMPT / TRANSCRIPT / SAY / FOUND / LOOK / KEEP / MODE /
 * STEP / BEEP / CLEAR) that each set the status text or the antenna colour AS A
 * SIDE EFFECT. Once the state machine owned the screen and the colour, those side
 * effects were not dead code -- they were actively fighting the new channels:
 *
 *   - `EVT STEP WATCH` called antDuty(), which painted S6's RED negation blue.
 *   - `EVT MODE` called setStatus("eager"), which repainted the old three-button
 *     screen -- EAGER button and all -- over the participant UI.
 *
 * Both were patched with guards (`hueOwned`, `if (!uiMode)`) before being deleted.
 * The guards are gone too: there is now exactly one owner per channel, so there
 * is nothing to arbitrate.
 *
 * LINK: USB serial @ 115200, line-based, '\n'-terminated.
 *
 *   Laptop -> CoreS3
 *     EVT UI <screen>      one of: idle recording waiting heard planning
 *                          tracking notthat noticed error black hello
 *                          (states.py SCREENS; `hello` is the greeting)
 *     EVT NOTICED <n>      session cumulative count, shown on `noticed`.
 *                          The LAPTOP owns this number: it owns the feed, so one
 *                          source of truth, and it survives a reboot here.
 *     EVT LED <0-255>      antenna level, streamed from the clip's `led` column
 *                          for accents synced to the motion. Falls back to the
 *                          local breath after 500 ms of silence, so a stalled
 *                          link is not a frozen LED.
 *     EVT HUE <WARM|COOL|RED|SUMMON|SPENT>  colour = which KIND of state
 *       (GREEN/ALARM still accepted -- old names, new colours)
 *     EVT SFX <name>       curious ack shutter puzzled excited lost | NONE
 *     EVT LEVEL <0-100>    mic level for the recording bar
 *     EVT VOL <0-255>      speaker volume; 0 for a silent run
 *     EVT NAME <text>      what the participant called it. ASCII only (the GFX
 *                          font is 32..126). Shown on `idle`, and slid in once on
 *                          `hello`. Data, not firmware: one flash teaches the
 *                          command, every later name is a serial line.
 *     EVT REST             end of a run: go quiet, back to idle + warm breath
 *     EVT PING             -> `IN PONG cores3_sidekick v6`
 *
 *   CoreS3 -> Laptop
 *     IN PTT_DOWN / IN PTT_UP     the green button, held
 *     IN OK                       the green button on `noticed` -- OR a TAP on the
 *                                 red one, from any screen (see uiTouch)
 *     IN STOP                     the red button HELD for STOP_HOLD_MS. A tap on
 *                                 it is a mis-touch and sends IN OK instead, so
 *                                 that brushing it cannot discard the task.
 *     IN BODYTAP                  touch sensor = "not that one"
 *     IN PONG ...                 identity, on request
 *
 * Board: M5CoreS3  ·  Lib: M5Unified  ·  "USB CDC On Boot: Enabled"
 *
 * BUMP THE VERSION STRING FOR ANY CHANGE THE LAPTOP CANNOT OBSERVE -- a new
 * command, a changed colour, a moved button. Not only for the protocol.
 *
 * v3 was cut when SUMMON and SPENT were ADDED. SPENT's value then changed from
 * blue to amber inside v3, and because the string did not move, cores3_link's
 * version check reported a match against a board still carrying the blue. The
 * check was built to answer "did I reflash" and it answered "yes" wrongly,
 * which is worse than not having it. Keep it in step with cores3_link.py's
 * FIRMWARE_V.
 */

#include <M5Unified.h>

// EVERY struct used in a function signature belongs up here, above the LAST
// #include in the file (which is ChainableLED.h, a few lines down -- not this
// one). The .ino preprocessor generates a prototype for every function in the
// sketch and injects them all immediately after that last #include; a type
// defined further down does not exist yet at that point, so the prototype is
// what fails, not the definition. Hence "error: 'X' does not name a type"
// pointing at a line that looks perfectly fine.
//
// Note hit this first; UiBtn hit it next, for the same reason. If you add a
// struct and pass it to anything, put it here.
struct Note  { uint16_t hz; uint16_t ms; };
struct UiBtn { const char* id; int x, y, w, h; uint16_t col; const char* label; };

void sfxStart(const Note* seq, int n);
void sfxTick();
void sfxByName(const String& n);
void uiSet(const String& name);
void uiDraw();
void uiTick();
void uiTouch();
bool uiHit(const UiBtn& b, int x, int y);

static const int SCREEN_W = 320, SCREEN_H = 240;

// ---------------- ANTENNA: Grove Chainable RGB LED v2.0 (P9813), Port B -------
#define USE_ANTENNA 1
#if USE_ANTENNA
  #include <ChainableLED.h>
  static const int LED_CLK = 8, LED_DATA = 9;
  ChainableLED leds(LED_CLK, LED_DATA, 1);
  int aR = 255, aG = 242, aB = 224;             // warm at boot (= HUE WARM)

  // The clip streams the LEVEL; the colour comes from the state. Local breathing
  // is only a FALLBACK -- if no level has arrived for A_EXT_TIMEOUT the board
  // breathes on its own, because a stalled link should leave the robot looking
  // alive rather than frozen mid-flash. A frozen LED reads to a participant as
  // "it broke"; a breath reads as "still here".
  int aExt = -1;
  uint32_t aExtAt = 0;
  const uint32_t A_EXT_TIMEOUT = 500;

  // DO WHAT init() DOES, RATHER THAN CALLING IT.
  //
  // "ChainableLED has no member named 'init'" is a LIBRARY-VERSION error, not a
  // sketch error: it appears the first time this file is compiled on a machine
  // whose ChainableLED differs from the one that last flashed the board.
  // pjpmarques/ChainableLED exposes init(); several forks do the same work in
  // the constructor and never declare it. Both are correct libraries, and
  // hard-coding either choice makes the board flashable from exactly one desk.
  //
  // The obvious fix -- an overload pair on decltype(l.init()) -- CANNOT BE USED
  // HERE. See the note at the top of this file: the .ino preprocessor generates
  // a prototype for every function in the sketch, and it drops the
  // `template <typename T>` line when it does, so the injected prototype
  // references an undeclared T. That surfaces as "'l' was not declared in this
  // scope" pointing at a template that is perfectly valid C++. NO TEMPLATE
  // DEFINED IN A .ino SURVIVES THIS. Put one in a .h beside the sketch if it is
  // ever genuinely needed.
  //
  // So: no detection at all. init() only sets the two pins to OUTPUT and blanks
  // the strip, which is safe to do directly and harmless to repeat if the
  // constructor already did it. setColorRGB is the one call both versions
  // agree on, and antennaTick() below already depends on it.
  void antennaInit() {
    pinMode(LED_CLK, OUTPUT);
    pinMode(LED_DATA, OUTPUT);
    leds.setColorRGB(0, 0, 0, 0);
  }
  void setAntennaHue(int r, int g, int b) { aR = r; aG = g; aB = b; }
  void setAntennaLevel(int v) { aExt = constrain(v, 0, 255); aExtAt = millis(); }
  // The fallback breath must BE S1_IDLE's envelope, not a second, louder one.
  // It stands in for the idle state, so anything else makes the handover between
  // "laptop streaming" and "board on its own" visible -- and it was: the old
  // fallback ran 0.25..0.80 (64..204 of 255) while S1's authored envelope is
  // 0.8..2.5 on the generator's 0-8 Strength scale, i.e. 26..80. The board's
  // default was two and a half times brighter and wider than the design, so the
  // moment a clip took over the antenna got DIMMER. It read as the authored
  // envelope not working at all.
  //
  // These two numbers are tied to generate_s1_idle.py's LED_LO / LED_HI and
  // export_clip.py's LED_FULL = 8.0:  0.8/8 = 0.10,  2.5/8 = 0.31.
  // If S1's LED range changes, change these with it.
  static const float FB_LO = 0.0375f;         // = S1 LED_LO 0.30 / LED_FULL 8.0
  static const float FB_SPAN = 0.275f;        // up to S1 LED_HI 2.5 / 8.0 = 0.3125
  static const float FB_MS = 800.0f;          // 2*pi*800 = 5.0 s, S1's mean breath
  // The floor dropped from 0.10 to 0.0375 because the breath was not reading.
  // PWM is linear in luminance and perceived brightness goes roughly as L^0.43,
  // so 26..80 of 255 is only a 1.6x PERCEIVED swing. 10..80 makes it 2.5x for
  // the same peak. Lower than this starts to look like a fault rather than idle.

  void antennaTick() {
    uint32_t m = millis();
    float s = (aExt >= 0 && (m - aExtAt) < A_EXT_TIMEOUT)
              ? aExt / 255.0f                                     // clip-driven
              : FB_LO + FB_SPAN * (0.5f + 0.5f * sinf(m / FB_MS)); // = S1 idle
    leds.setColorRGB(0, (uint8_t)(aR * s), (uint8_t)(aG * s), (uint8_t)(aB * s));
  }
#else
  void antennaInit() {}
  void setAntennaHue(int, int, int) {}
  void setAntennaLevel(int) {}
  void antennaTick() {}
#endif

// ---------------- BODY TAP (TTP223 capacitive: SIG/VCC/GND) -------------------
// SIG->TAP_PIN, VCC->3V3 (NOT 5V, ESP32 GPIO is not 5V-tolerant), GND->GND.
#define USE_TAP   1
#define TAP_SRC   1         // 1 = external TTP223 ; 2 = onboard IMU knock
static const int TAP_PIN = 17;     // Grove Port C; avoid 8/9 (antenna)
static const float TAP_G = 1.4f;   // (TAP_SRC 2) accel jump for a tap, g

void tapInit() {
#if USE_TAP && TAP_SRC == 1
  // pulldown: an unconnected pin then reads a steady 0. Random 0/1 in the
  // monitor means SIG is not actually reaching this pin.
  pinMode(TAP_PIN, INPUT_PULLDOWN);
#endif
}

void checkTap() {
#if USE_TAP
  static uint32_t tlast = 0;
 #if TAP_SRC == 1
  static bool last = false;
  bool now = digitalRead(TAP_PIN);
  if (now && !last && millis() - tlast > 250) {
    Serial.println("IN BODYTAP"); tlast = millis();
  }
  last = now;
 #else
  static float px = 0, py = 0, pz = 0;
  float ax, ay, az;
  if (M5.Imu.getAccel(&ax, &ay, &az)) {
    float d = fabsf(ax - px) + fabsf(ay - py) + fabsf(az - pz);
    px = ax; py = ay; pz = az;
    if (d > TAP_G && millis() - tlast > 400) {
      Serial.println("IN BODYTAP"); tlast = millis();
    }
  }
 #endif
#endif
}

// ---------------- SFX: per-state sounds, non-blocking ------------------------
// Scheduled rather than played with delay(), because loop() also drives the LED:
// a blocking chirp at a state change freezes the light at exactly the moment both
// channels are meant to be saying the same thing.
//
// The vocabulary mirrors the motion rather than decorating it:
//   curious  rises   a question, matching the turn toward you (S2, unused now)
//   ack      falls   affirmation, same downward accent as the nod (S3)
//   shutter  click   one capture, fired off the LED flash so they cannot drift (S4)
//   puzzled  ends up an unresolved question (S6)
//   excited  rises   calling you over from across the desk (S7a)
//   lost     wanders odd intervals, drifting down, unresolved (S8)
const int SFX_MAX = 10;
Note sfxSeq[SFX_MAX];
int sfxLen = 0, sfxIdx = 0;
uint32_t sfxNextAt = 0;

void sfxStart(const Note* seq, int n) {
  sfxLen = (n < SFX_MAX) ? n : SFX_MAX;
  for (int i = 0; i < sfxLen; i++) sfxSeq[i] = seq[i];
  sfxIdx = 0;
  sfxNextAt = millis();
}

void sfxTick() {
  if (sfxIdx >= sfxLen) return;
  uint32_t m = millis();
  if (m < sfxNextAt) return;
  Note n = sfxSeq[sfxIdx++];
  if (n.hz) M5.Speaker.tone(n.hz, n.ms);
  sfxNextAt = m + n.ms;
}

// two notes close together read as ONE blip that rises -- tone() cannot glide
const Note SFX_CURIOUS[] = {{1000, 35}, {1400, 55}};
const Note SFX_ACK[]     = {{1400, 70}, {1000, 110}};
const Note SFX_SHUTTER[] = {{2600, 22}};
const Note SFX_PUZZLED[] = {{1000, 70}, {760, 70}, {1180, 130}};
const Note SFX_EXCITED[] = {{1000, 55}, {1350, 55}, {1800, 85}, {0, 55}, {1800, 120}};
// deliberately non-diatonic and irregular: "weird" comes from intervals that do
// not resolve, not from being loud
const Note SFX_LOST[]    = {{820, 150}, {605, 110}, {700, 170}, {515, 210},
                            {0, 110}, {560, 95}};

void sfxByName(const String& n) {
  String k = n; k.toUpperCase();
  if      (k == "CURIOUS") sfxStart(SFX_CURIOUS, 2);
  else if (k == "ACK")     sfxStart(SFX_ACK, 2);
  else if (k == "SHUTTER") sfxStart(SFX_SHUTTER, 1);
  else if (k == "PUZZLED") sfxStart(SFX_PUZZLED, 3);
  else if (k == "EXCITED") sfxStart(SFX_EXCITED, 5);
  else if (k == "LOST")    sfxStart(SFX_LOST, 6);
  else if (k == "NONE")    { sfxLen = sfxIdx = 0; }
}

// ---------------- PARTICIPANT UI: nine screens, at most two buttons ----------
// Two rules the layout ENFORCES rather than documents:
//   * GREEN IS ALWAYS LEFT AND AFFIRMATIVE, RED ALWAYS RIGHT AND STOP. A
//     participant should never have to read a button to know what it does, and
//     moving them between screens would destroy that.
//   * TOUCH ONLY HITS BUTTONS THAT ARE ACTUALLY DRAWN. A STOP-only screen has no
//     phantom PTT, so a stray thumb cannot start a recording nobody sees.
//
// Nine screens for eight states: `waiting` belongs to S2 after the button is
// released, when the robot's behaviour has not changed but what it is telling you
// has.
String uiScreen = "idle";
int    noticedN = 0;
int    recLevel = 0;
uint32_t recDrawnAt = 0;

// UiBtn itself is defined at the top of the file -- see the note there.
const int UI_MAX_BTN = 2;
UiBtn uiBtns[UI_MAX_BTN];
int uiNBtn = 0;
int uiDown = -1;

static const uint16_t COL_GREEN = 0x2604;
static const uint16_t COL_RED   = 0xB000;

void uiLayout() {
  uiNBtn = 0;
  if (uiScreen == "idle") {
    // the one screen a participant reads while deciding to act, so both are big
    // "PTT" is the id the loop speaks; the LABEL is what a participant reads,
    // and it is not the same word. Push-To-Talk is radio jargon -- nobody who
    // has not used a walkie-talkie decodes it, and the study is not the place
    // to find that out.
    //
    // The label says HOLD rather than TALK or RECORD because the failure it has
    // to prevent is specific: this button is a LATCH (PTT_DOWN / PTT_UP), and
    // every tap-to-record convention on earth says press once and let go. A
    // participant who taps produces an instant down-up pair, an empty
    // transcript, and S8 -- and reads that as the microphone being broken
    // rather than as having used the button wrongly. The record dot drawn above
    // it carries "this is the speaking one"; the word carries "and do not let
    // go", which the dot cannot say.
    uiBtns[uiNBtn++] = {"PTT",  8, 132, 150, 100, COL_GREEN, "HOLD"};
    uiBtns[uiNBtn++] = {"STOP", 166, 132, 146, 100, COL_RED, "STOP"};
  } else if (uiScreen == "recording") {
    // nothing: the finger is already on the button that matters
  } else if (uiScreen == "noticed") {
    // OK ALONE. This is the screen the participant is looking at when the robot
    // has just called them over, which makes it the one they are most likely to
    // touch and the worst place to keep a cancel: STOP discards the watch-spec,
    // and during the study's work phase that voids every scripted event still to
    // come. There is nothing to cancel here anyway -- the finding is already in
    // the feed, and OK is the whole of what this screen asks for.
    //
    // Losing STOP from this screen loses nothing: S7 returns to S5 on OK or on
    // its own timeout, and `tracking` still carries a hold-to-stop.
    uiBtns[uiNBtn++] = {"OK", 88, 168, 144, 64, COL_GREEN, "OK"};
  } else if (uiScreen == "error") {
    // GREEN, AND A TAP, because S8 is the one screen where getting out IS the
    // affirmative act. A hold would be the wrong gesture to demand of somebody
    // looking at a robot that has just failed, and there is no task left to
    // protect -- S8 is reached when a request was unusable or a plan never
    // arrived, so nothing is discarded by leaving.
    //
    // The laptop already gives up by itself after ST.S8_RECOVER_S (16 s). This
    // makes the same exit reachable immediately by whoever is watching.
    uiBtns[uiNBtn++] = {"OK", 88, 168, 144, 64, COL_GREEN, "OK"};
  } else if (uiScreen == "black") {
    // S1 FILMING ONLY (`EVT UI black`, sent by tools/film_s1.py): a screen
    // with a state word on it is a printed answer key -- the study's rule is
    // that the STATE is read from movement/light/sound, so the stimulus must
    // not caption itself. Pure black, ZERO buttons (the plain else below would
    // add a STOP, and a phantom touch target on an unlabeled screen is worse
    // than none). The antenna and speaker are separate channels and keep
    // running. Never used in a live session.
  } else {
    uiBtns[uiNBtn++] = {"STOP", 88, 168, 144, 64, COL_RED, "STOP"};
  }
}

void uiDrawBtn(int i) {
  const UiBtn& b = uiBtns[i];
  bool down = (uiDown == i);
  M5.Display.fillRoundRect(b.x, b.y, b.w, b.h, 10, down ? TFT_WHITE : b.col);
  M5.Display.drawRoundRect(b.x, b.y, b.w, b.h, 10, TFT_DARKGREY);
  M5.Display.setTextColor(down ? TFT_BLACK : TFT_WHITE);
  M5.Display.setTextDatum(middle_center);
  int cx = b.x + b.w / 2;
  // The speaking button carries a record dot above its label. Icon AND word:
  // the dot says which button this is at a glance, the word says what to do
  // with it, and neither does the other's job. See the note in uiLayout().
  if (String(b.id) == "PTT") {
    M5.Display.fillCircle(cx, b.y + 34, 15, down ? TFT_BLACK : TFT_WHITE);
    M5.Display.setTextSize(3);
    M5.Display.drawString(b.label, cx, b.y + b.h - 28);
  } else {
    M5.Display.setTextSize(3);
    M5.Display.drawString(b.label, cx, b.y + b.h / 2);
  }
}

void uiDrawBar() {
  const int x = 30, y = 100, w = SCREEN_W - 60, h = 34;
  M5.Display.drawRoundRect(x, y, w, h, 6, TFT_DARKGREY);
  int fill = (w - 6) * constrain(recLevel, 0, 100) / 100;
  M5.Display.fillRect(x + 3, y + 3, fill, h - 6, COL_GREEN);
  M5.Display.fillRect(x + 3 + fill, y + 3, (w - 6) - fill, h - 6, TFT_BLACK);
}

// ---------------- THE NAME IT WAS GIVEN ---------------------------------------
//
// Sent from the laptop as `EVT NAME <text>`, not compiled in: the participant
// names it in the introduction and the researcher types it there and then. One
// flash teaches the board the command; after that a new name is a serial line.
//
// ASCII ONLY, and that is not a shortcut. The default GFX font is 32..126, so a
// non-Latin name comes out as blanks and does so SILENTLY. The study asks for
// Latin names for this reason.
String botName = "";

// Big for a short name, smaller for a long one, rather than one size that either
// wastes the screen or overruns it. Char cell is 6*size px wide; 300 px usable.
int nameSize(const String& n) {
  int len = n.length();
  if (len <= 10) return 4;
  return 3;                       // 16 chars; longer is truncated by drawName
}

// A FACE PER SCREEN. Small, ASCII, and second to the words -- it is there so the
// thing reads as somebody rather than as a status line. `recording` gets none:
// the participant is mid-sentence with a finger on the button and needs the dot,
// the word and the level bar, not a fourth thing to look at.
const char* uiFace() {
  if (uiScreen == "idle")      return "-_-";      // asleep; the zzz is drawn beside it
  if (uiScreen == "waiting")   return "._.";
  if (uiScreen == "heard")     return "^o^";
  // planning: NO FACE. This is the one screen whose job is to send the eye
  // ELSEWHERE -- the head is sweeping the room and that movement is the message.
  // A face here competes with the thing it is meant to introduce.
  if (uiScreen == "tracking")  return "o_o";     // open, watching
  if (uiScreen == "notthat")   return ">_<";
  if (uiScreen == "noticed")   return "\\^o^/";  // the one it calls you over for
  if (uiScreen == "error")     return "x_x";
  return "";
}

void drawName(int x, int y) {
  String n = botName;
  if (n.length() > 16) n = n.substring(0, 16);
  M5.Display.setTextColor(TFT_WHITE);
  M5.Display.setTextDatum(middle_center);
  M5.Display.setTextSize(nameSize(n));
  M5.Display.drawString(n, x, y);
}

const char* uiText() {
  // "idle" was the state's name leaking onto the participant's screen. It is
  // accurate and it is not for them: it describes what the machine is not
  // doing. "ready" describes what they can do, which is the only thing this
  // screen is for.
  if (uiScreen == "idle")      return "ready";
  if (uiScreen == "waiting")   return "waiting...";
  if (uiScreen == "heard")     return "I heard you.";
  if (uiScreen == "planning")  return "planning...";
  if (uiScreen == "tracking")  return "tracking...";
  if (uiScreen == "notthat")   return "not that!?";
  if (uiScreen == "error")     return "error";
  return "";
}
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
void loop() {
  M5.update();
  antennaTick();
  uiTouch();
  uiTick();
  sfxTick();
  checkTap();

  static String buf;
  while (Serial.available()) {
    char c = (char)Serial.read();
    if (c == '\n') { handleLine(buf); buf = ""; }
    else if (c != '\r') buf += c;
  }
  delay(5);
}

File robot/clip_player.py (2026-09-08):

#!/usr/bin/env python3
"""
Non-blocking clip playback for the 3-DOF prototype.

One background thread owns the bus and plays clips on their own clock; the main
loop asks for state changes and reads status. Playback must not block, because
the conductor also has a camera to drain and a CoreS3 to poll -- and because a
blocking player makes the researcher's override key wait for the clip to end,
which is exactly when you most want it.

Two things this exists to protect:

* AUTHORED TIMING. Inside a clip the CSV's t_ms is honoured to the millisecond
  and late frames are dropped rather than sent late. The ease curves are the
  design contribution; re-timing them throws it away.
* SETTLED-ONLY VISION. The camera rides on the head, so a frame taken mid-move
  is motion-blurred and points somewhere that no longer matches the pose it will
  be attributed to. `settled_ms` reports how long the commanded pose has been
  unchanged, so the conductor can sample only while still. This falls out for
  free during S4's per-station dwells.

Standalone:
  export NOTICEBOT_PORT=/dev/cu.usbmodemXXXX
  python3 clip_player.py                 # walk the designed cycle
  python3 clip_player.py S7a             # one state, then hold
"""
import csv, os, sys, threading, time

# Run me directly: put the repo ROOT on the path so the packages import.
# (Kept as a two-line preamble rather than a helper module, because a
# bootstrap that itself needs importing defeats the purpose.)
sys.path.insert(0, os.path.dirname(os.path.dirname(
    os.path.abspath(__file__))))
from robot.scs import Bus, open_bus
from robot.pose import (JOINTS, IDS, CENTER, UNITS_PER_DEG, resolve, centre_units,
                       reach_deg, clamp_deg,
                  unit_to_deg,
                  move_ms, REAIM_DPS, COLLAPSE_DPS)
from robot import states as ST

DEFAULT_CLIPS = os.path.join(os.path.dirname(os.path.dirname(
    os.path.abspath(__file__))), "motion", "clips")
STREAM_HZ = 60          # command scheduler tick; clips are 30 fps
ARRIVE_TOL = 8          # units. Bigger than settling error, smaller than a jam.
# Flash detection is a Schmitt trigger, not a rising-edge difference. A flash
# takes several frames to climb (S4 goes 32 -> 96 -> 191 -> 223), so a plain
# "rose by more than X" test fires on each of those steps -- the shutter clicked
# twice per station. Crossing HIGH fires once; it will not fire again until the
# level has fallen back under LOW.
LED_FLASH_HIGH = 150   # of 255. S4's flash peaks at 223.
LED_FLASH_LOW = 90     # must fall below this to re-arm; S4 rests at 32.
LED_HEARTBEAT_S = 0.30  # must stay well under the firmware's 500 ms fallback,
                        # or a slow-changing stretch of an authored envelope
                        # silently hands the LED back to the local one


def trim_s4_return(frames, pan_slop_units=2):
    """Remove S4's return-to-template after its final shutter station.

    Returning to the template pan before the VLM answers visually claims a
    direction that has not been chosen. Find the last shutter rise and retain
    its full dwell up to the first real departure from that bearing.
    """
    rises, in_flash = [], False
    for i, frame in enumerate(frames):
        level = frame.get("led")
        if level is None:
            continue
        if level >= LED_FLASH_HIGH and not in_flash:
            rises.append(i)
            in_flash = True
        elif level <= LED_FLASH_LOW:
            in_flash = False
    if not rises:
        return frames
    last_rise = rises[-1]
    station_pan = frames[last_rise]["pan"]
    cut = len(frames)
    for i in range(last_rise + 1, len(frames)):
        if abs(frames[i]["pan"] - station_pan) > pan_slop_units:
            cut = i
            break
    return frames[:cut]


def shift_pan_centre(frames, to_deg, verbose=True):
    """Translate a clip's whole pan track so its centre lands on `to_deg`.

    For a clip whose pan is a SHAPE rather than a bearing. S6 shakes horizontally
    -- that shake is the negation, "not that one" -- and it was authored around
    +25 because it was drawn as a continuation of watching. Where the shake sits
    is a separate question from what it does, and only the first one moves here.

    A TRANSLATION, NOT A REMAP. `remap_share_pan` rescales between two plateaus,
    which is right when a clip crosses between two named places; applied to a
    shake it would change the amplitude, and S6's amplitude is calibrated against
    the pan floor (1.76 deg) -- scale it down and the negation stops registering
    as movement at all. Adding a constant cannot do that: every excursion, every
    velocity and the whole clock survive untouched.

    The centre is taken as the MIDPOINT OF THE TRAVEL, not the first frame. A
    shake starts at one end of its own swing, so the first frame is an extreme;
    centring on it would leave the gesture lopsided about the person by half the
    amplitude.

    S7b (clip v5) is the OPPOSITE case and lands here anyway: its pan is a pure
    bearing, held for the whole loop, with no shape at all. A constant is
    trivially its own midpoint, so the same arithmetic aims it -- but note that
    nothing is being centred and the `[face]` in the log line is a misnomer
    there: S7b points at the FINDING, not at the person. It is routed here
    rather than through `remap_share_pan` because a two-point rescale needs two
    plateaus, and applying one to a single-plateau curve would work by accident.
    See the header of generate_s7_beckon.py for why the second plateau went.
    """
    if not frames:
        return frames
    pans = [unit_to_deg("pan", f["pan"]) for f in frames]
    centre = (min(pans) + max(pans)) / 2.0
    delta = float(to_deg) - centre
    if abs(delta) < 0.05:
        return frames
    out = []
    clamped = 0
    for f, p in zip(frames, pans):
        g = dict(f)
        # Same deg -> raw -> commanded path as remap_share_pan's to_unit(), so
        # the two retargeters cannot drift apart by half a unit.
        u, was = resolve("pan", max(0, min(1023,
                         round(((p + delta) + 150.0) / 300.0 * 1023))))
        clamped += bool(was)
        g["pan"] = u
        out.append(g)
    if verbose:
        print(f"[face] pan centre {centre:+.1f} -> {to_deg:+.1f} deg "
              f"({delta:+.1f}), shape unchanged"
              + (f"   !! {clamped} frames CLAMPED -- the person is outside the "
                 f"pan limits from here" if clamped else ""))
    return out
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

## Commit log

2026-07-26 Restructure into layers; drop the v1 hardware
    The repo now holds the whole v2 system, split so that two people can work at
    once without meeting in the same file:
    robot/ servo bus, calibration, clip playback, firmware, CAD
    motion/ Blender sources, clip generators, exported CSVs
    perception/ detectors, pose, the 11-row relation engine, overlay
    planning/ the VLM planner, the relevance layer, the sweep
    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
    [1_base_lower.stl, 2_hub.stl, 3_neck_lower_coupler.stl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]
2026-07-27 docs: add notations, remove stl files.
    [1_base_lower.stl, 2_hub.stl, 3_neck_lower_coupler.stl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]
2026-08-01 fix blender 3d model based on physical model design
    [breath_test.py, calibration.py, calibration_backup_0731.py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]
2026-08-04 Harden Gemini E2E state and audit flow
2026-08-04 Reset noticed session state on stop
    [session_flow.py, storyboard.py]
2026-08-04 fix: CoreS3 detection resets the board; gdino tokenizer version shim
    [cores3_link.py]
2026-08-05 LED palette from the literature, firmware v4, CoreS3 wording
    Colours were chosen by eye and two of them collided: `warm` (idle) and
    `alarm` (error) sat 5 degrees apart on the hue wheel, so "fine" and "stuck"
    were one colour on a diffused LED. Derivations now live in
    robot_motion/LED_COLOR_DESIGN.md; four of five values come from published
    results rather than taste.
    RED 0/100/100 = Loffler's validated anger
    SUMMON 45/100/100 = Loffler's validated joy. Was GREEN, which is the
    low-arousal positive corner AND the OK button eight
    centimetres away -- one colour, two referents.
    SPENT 30/0.95 = an ember. Was "alarm" amber at V .94, brig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
    [S2_LISTEN.csv, S3_ACK.csv, S4_PLAN.csv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]
2026-08-05 judge: one verdict on the moment. 142s -> 2.3s on recorded calls
    Judge calls ran 40-278 s against a planner at 5-17 s -- same model, same five
    1280x720 frames (4.6 MPx either way; the KB difference is compressibility), a
    LONGER prompt and a DEEPER schema. Model, image tokens, prompt size, schema
    depth, thinking_level and connection contention were each ruled out by
    inspection or data, so what was left was what the judge was being ASKED.
    Replaying the ten slowest recorded calls through the new prompt: median
    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
2026-08-05 three things that could never fire, and the aim they were hiding
    S7 never fired. A re-plan while the judge was in flight bumped
    plan_generation, so the reply -- selected_index 0, both cards confirmed,
    "The user is holding and reading a book" -- was dropped as stale. Observed on
    hardware: judge started 15:01:10, the 60 s idle timer fired mid-call, the
    answer arrived 15:03:04 and went in the bin. A judge in flight is not an empty
    angle, so the idle clock is postponed while one is out.
    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
2026-08-11 S7 v6: rest on S5b's watching pose; S8 bows 15 deg deeper
    S7 used to hold a crane 10 degrees below the watching pose, and the storyboard
    then refused every panel taken during it -- POSE_TOL_DEG is 3, so a story that
    opened in S5b and continued through S7 was two different shots.
    The ten degrees was the epistemic escalation and it has not been dropped: it
    moved into the push. S7a is one 12-degree push and back, S7b is the same push
    three times, both resting exactly where S5b watches from. Four seams now measure
    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
    [S7a.csv, S7b.csv, S8_ERROR.csv]
2026-08-11 judge: strip deixis, widen the window, say why on a rejection, judge only the card that fired
    Four faults, all of them found by watching real events be rejected.
    LEFT AND RIGHT. The planner resolves "the right board" against every view it
    swept and the CV gate enforces the box that comes out; the judge is handed five
    frames and no pan angle, so it re-resolves the word against the PICTURE and gets
    a different answer. Measured on a real drawing event: "draws on the right board"
    failed twice, "draws on the board" passed twice, and a paragraph telling it the
    head turns failed twice more -- which is why the word is removed rather than
    explained. "in front of" and "behind" are kept: those hold fr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
2026-08-11 perception: hands-on tests the HAND; a turned body is not a small one
    Reported as "I touched the plant for many seconds before it fired", and the log
    agreed on every frame: "no wrist is inside any object box".
    THE HAND, NOT THE JOINT IT HANGS OFF. Relation 9 is called hands-on and was
    testing the WRIST, which is a forearm behind where a person actually touches
    something. BlazePose 17-20 are the pinky and index knuckles; they were in the raw
    landmark array all along and simply never collected. Wrists stay unconditional,
    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
2026-08-11 planner: one relation per entry, on is part of what makes a card distinct, no bare approach
    Three faults, each of which cost a whole session.
    DUPLICATE ENTRY. The uniqueness key was built from relation ids alone, so two
    cards watching the same ACTION on different THINGS were called duplicates and the
    entire plan was thrown out. Observed on "Look at people drawing on the white
    board. Look at people touching my plants." -- which is the shape the study asks
    every participant for. Both retries produced the same correct pair and both
    failed; the session went to S8 and back to idle with nothing to watch. Of the
    three pairs the card offers, this was the only one that could never compile, and
    it is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
2026-08-11 storyboard: one continuous shot, at the camera's own resolution
    "Even when I do not move at all, every story is 3 shots."
    The keyframe test was not broken. It asks whether the picture changed, and the
    camera is mounted ON THE HEAD while a story opens at the instant S7 starts
    swinging it -- so "changed" was true at every interval no matter how still the
    room was. The saved strip that settled it: panel 1 blurred mid-turn, panel 2 the
    participant facing the lens because the robot had just turned to face her, panel
    3 a wall with her shoulder at the edge. The narration was written from panel 2
    and described her REACTING TO THE ROBOT, which is the one thing the feed is not
    for.
    Panels are now ta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
    [storyboard.py]
2026-08-11 review page: what the participant reads in protocol section 6
    One HTML file per session, rebuilt by feed.publish on every report, served to a
    tablet beside the robot. The summons is the moment someone walks over to look;
    until now it led to a 320x240 board showing a number, because the CoreS3 protocol
    has no image channel.
    WHAT IS DELIBERATELY NOT ON IT: judge_agreed, the truth vector, relation ids and
    names, worth, plan_generation, the card label. RQ4 asks whether people can read
    the ROBOT; a page carrying the machinery invites them to grade the machinery
    instead, and that leak would not look like a bug -- it would look like a slightly
    more informative page. There is a test that fails if a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
    [feed.py, review.py]
2026-08-11 CoreS3 v5: STOP is hold-to-stop, OK alone on `noticed`, OK to leave S8
    STOP is a CANCEL -- it discards the watch-spec and returns to S1 -- and during
    the fifteen-minute work phase the participant sits alone with this screen having
    been told to do whatever feels natural, with the red button next to the green
    one. One brush ended the task, and it fired on touch-DOWN, so not even a
    deliberate press was required. Every scripted event after that point could then
    fire for nobody.
    It cannot simply be deleted: PTT is accepted only from S1_IDLE and STOP is the
    only route there, so the delegating phase needs it for a second brief and for
    every correction. So tap and hold are separated in the FIRMWARE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
    [cores3_link.py, cores3_sidekick.ino, session_flow.py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]
2026-09-07 Pilot hardening: nothing that reached somebody is thrown away
    Seven ways a real finding could vanish, all found by running the robot
    during the 08-12..08-18 pilots. Each had a test added with it.
    WATCH EXECUTOR
    - The focus gate is folded into step() instead of filtering its result.
    truth[9] is global ("a hand is on SOMETHING"), so a hand resting on the
    wrong object used to spend the cooldown and eat the rising edge for a
    card that never fired.
    - unfire()/recool() matched entries by object identity, but the loop hands
    back a dict(e) copy -- so both silently did nothing in the live loop.
    Reported as "suppressed still shows 14s". They match on content now.
    - Firing no longer requires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
    [cores3_link.py, cores3_sidekick.ino, review.py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]
2026-09-08 Exhibition build: the iPad is the interface, the robot stays as it was
    The stand is in Japanese, the system is in English, and nothing about the
    robot changes -- its screen keeps the English words and the faces from
    the study build, and the faces are what carry it: a sleeping face and a
    woken one need no translation. Everything a visitor reads is on the
    tablet, so translating the stand means translating one file.
    ONE GESTURE, TWO MEANINGS. The TTP223 on the head already reached the
    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
2026-09-08 DEMO RUNBOOK: wiring, one process all day, the iPad, and the venue-wifi trap
2026-09-08 print the tablet's address at startup, from the routing table not en0
2026-09-08 The tablet never left the choose screen, and the choice was too small to read
    THE SWEEP SCREEN NEVER APPEARED. The booth fields were published inside the
    `view is None` arm -- the fallback for a detector that failed to load --
    so on every real run they never executed. flow_state stayed "", which
    matches no state, so `phase` fell through to `choose` and stayed there for
    the whole session: no five frames, no red frame, no notice prompt. Nothing
    raised; an unset string is just a string. Moved above the branch, and the
    test asserts the POSITION rather than the presence, because presence was
    never the problem.
    THE CHOICE IS NOW THE WHOLE SCREEN. A visitor reads it standing, from
    about a metre, i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
2026-09-08 Waking it must not take the choice away; a strip of faces instead
    S2_LISTEN had its own screen, so touching the head -- the one gesture that
    starts the demo -- replaced both task buttons with a "woken" page at the
    exact moment the visitor had to pick one. It now stays on `choose`.
    What a state change is worth here is a glance, not a screen, so the state
    lives in a small strip along the top. The faces are copied from the
    firmware's uiFace(): -_- ._. ^o^ o_o >_< \^o^/ . Two surfaces, one
    vocabulary -- a visitor looking from the tablet to the robot sees the
    same thing twice rather than learning a second code. S4 shows a looking
    mark, not an expression, because planning wears no face on the boa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
2026-09-08 Two bugs from the first tablet run: no sweep, and type that never grew
    IT NODDED AND WENT BACK TO SLEEP INSTEAD OF SCANNING. `arm_next` overrides
    the NEXT `then`, and is consumed when a one-shot FINISHES -- but an
    interrupted clip never reaches a `then`, so the arming survived and
    hijacked the following transition instead. The head tap arms S1_IDLE and
    plays S2; the tablet is right there, so the visitor picks a task while S2
    is still running; S2 is cut short, S3_ACK finishes, and the stale override
    replaces its `then` (S4_PLAN) with S1_IDLE. Nod, sleep, no sweep -- the
    entire middle of the demo. Cleared on the interrupted path in clip_player,
    which fixes the class rather than this instance: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
    [clip_player.py]
2026-09-08 Scanning and watching are one screen, and the red frame follows the aim
    "tracking..." over an empty page told a visitor less than the robot
    standing in front of them already was. The question in both phases is the
    same -- which way is it looking -- so the five stations now stay up from
    the sweep through the watch: cells fill as the head captures them, the
    boxes and the red frame land with the plan, and the frame stays.
    And it MOVES. The red frame is the station nearest where the robot is
    ACTUALLY AIMED, not the one the sweep scored highest. Those agree until
    somebody taps the head, and that tap is the whole Correct beat -- reddening
    the sweep's own pick would have left the frame where it wa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
2026-09-08 The bottom of the page was being cut off, and the type is now width-driven
    #app had TWO live rules: height:100% from one and flex:1 from the other.
    With the state strip above it that runs the page past the viewport, and
    overflow:hidden then cut the bottom away -- which is the grid on the room
    screen and the second button on the choose screen. One rule now, and a test
    counts them.
    The choice is sized off the WIDTH, clamp(48px,9vw,132px), because width is
    the dimension a two-line Japanese sentence actually runs out of; the
    previous min(vw,vh) collapsed to its 40px floor in a small laptop window,
    which is exactly where it was being looked at. Floor raised to 48 and the
    test asserts a floor rat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
2026-09-08 The report is the strip itself, swiped; the wall is a chip in the corner
    A STORY IS SEVERAL MOMENTS IN A ROW, and the storyboard already composites
    them into one wide jpg. Showing a squashed thumbnail of it threw away the
    thing that makes a story a story -- that it went on. The frame is now shown
    at full height in a sideways-scrolling strip, with the sentence underneath
    where a caption belongs, and a swipe hint when there is more than one panel.
    THE WALL BUTTON MOVED into the top row, right-hand end, at the size of a
    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
2026-09-08 OK returns to watching, and the rule is shown in the sixth cell
    OK STILL WENT BACK TO SCAN, and the cause was my own previous fix. Clearing
    the armed override whenever a clip was interrupted looked principled, but OK
    arms S5B_TRACK and then requests S3_ACK -- and that request interrupts S7b,
    so the arming meant for S3_ACK was wiped a microsecond after it was made.
    S3_ACK fell back to its own `then`, S4_PLAN, and the robot re-scanned.
    The two failures pull opposite ways, so the rule cannot be about
    interruption: only the CALLER knows which clip an override was meant for.
    It now says so by the order it calls them -- request() clears any pending
    override, so every caller requests first and arm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
    [clip_player.py, session_flow.py]
2026-09-08 The watched direction is live, and the nod loses its screen
    THE NOD DOES NOT GET A PAGE. 1.7 s that appears and vanishes is a flash, not
    information -- and S3_ACK happens twice, after a choice and after OK, so any
    one screen would be wrong in one of them. The strip shows ^o^ and the page
    stays where the visitor's attention already is: about to sweep, or reading
    the report they just acknowledged.
    THE RED CELL IS THE CAMERA NOW, not a photograph taken during the sweep.
    Tapping it fills the screen with the rule beside it; tapping again puts it
    back in the grid. The other four stay as sweep stills -- one moving picture
    is where the robot is looking, five would be a video wall.
    The stream lives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
2026-09-09 The demo loop did not move: player.start() was never called
    `request()` only records what the player SHOULD be doing; the clip is fed to
    the bus by a worker thread that start() spawns. Without it the M5 screen
    changed on cue while the head never moved and no sound played -- which looks
    exactly like a servo-power or wiring fault, and is neither. It gets a test
    rather than a comment for that reason.
    And a beat now WAITS FOR ITS CLIP before it starts holding. Sleeping for the
    hold alone cut S2's 1.97 s turn off after 1.2 s, and an interrupted gesture
    reads as a twitch rather than as a turn. Clip lengths are measured from the
    CSVs at startup rather than kept in a table: the state table says whi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
    [attract.py]
2026-09-09 tools/split_strip.py: cut a storyboard strip back into full-resolution panels
2026-09-14 tablet: English, and the request goes back to the robot
    The exhibition build put three tappable Japanese sentences on the iPad because a
    stranger at a stand has ninety seconds and no briefing. A participant has a
    moderator and seven minutes, and a menu decides for them the one thing the study
    is asking them to decide. So the request is spoken again, holding the button, in
    their own words -- and what the tablet shows during that moment is what Whisper
    HEARD, large, as it lands.
    That screen is the point of the change. A misread caught while the sentence is
    on screen costs five seconds; the same misread caught when the head sweeps the
    wrong way costs the turn, and until now it could only be ca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
2026-09-23 figures: the state figure, rigged from the drawing rather than from code
    The per-state motion figure was first drawn with shapes invented in code, and
    it looked like a diagram of some other robot. These two tools replace that:
    trace_robot_parts.py lifts Cassie's drawing off its background and cuts it at
    the two joints, make_state_figure.py rotates those pieces by the angles read
    out of motion/clips/*.csv at draw time.
    Her line, the clips' angles; neither is guessed. Re-exporting the clips and
    re-running the script is the whole update procedure, which is the point --
    STUDY_CLIP_AUTHORITY.md makes the CSVs the authority for every motion fact in
    the paper, and a figure drawn by hand starts acc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
